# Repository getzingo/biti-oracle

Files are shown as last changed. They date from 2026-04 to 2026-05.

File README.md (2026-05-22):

# Das Orakel von Selphi

Spaßprojekt für BITI Mobile Computing, Wahrsager-Automat mit problematischer Persönlichkeit. Die Schicksale werden von einem Large Language Model freier Wahl kreiert und über das grafische User Interface angezeigt.
Damit die Wahrsagungen individuelle bleiben, wird bei der Aktivierung durch einen Distanz-Messer auf einer dafür vorgesehenen Interaktionsfläche, die Distanz der Hand zum Sensor gemessen und die Temperatur der Handfläche. Kombiniert ergibt sich ein normalisierter Wert, der die Persönlichkeit des Orakels ergibt. Weiters werden die Ausgaben desselben Tages an das KI-Modell übermittelt, damit sich die Wahrsagungen immer voneinander unterscheiden.

Die Anforderungen sind sehr simpel gestaltet, eine interagierende Person soll durch die Text-Hinweise auf dem Bildschirm eine Lesung lostreten, nachdem die Generierung abgeschlossen ist, wird das Schicksal verlautbart und nach einer festgelegten Zeit gelangt das Programm wieder in den Startzustand zurück und wartet auf die nächste Aktivierung.

---

## Architektur

```mermaid
flowchart TB

    subgraph Raspberry
        direction TB
        A[Ultraschall Sensor</br>GPIO 16/12]
        B[Arduino</br>/dev/ttyUSB0]
        C[IR Temp Sensor</br>A6=OBJ A7=SUR]
        
        D[Pygame GUI]
        E[Fortune]
        F[DB]
        G[SensorManager]

        B --> C
        G --> B
        G --> A
        D --> E
        D --> G
        E --> F
    end
    E -->API
    API --> DB
    API --> LLM

```

**SensorManager** (`utils/sensor_manager.py`) ist die zentrale Schaltstelle. Wenn `BOARD=raspi` gesetzt ist, werden echte Sensoren verwendet — sonst simulierte Zufallswerte für Entwicklung und Tests.

**Fortune** (`utils/classes/Fortune.py`) orchestriert die Generierung: Sensorwert → Persönlichkeit (mood) → Prompt → REST API → Ergebnis. Läuft in einem eigenen Thread, damit die GUI nicht blockiert.

**Fallback**: Schlägt die API fehl, greift das Orakel auf frühere, lokal gespeicherte Wahrsagungen aus der SQLite-Datenbank zurück.

## Hardware Komponenten

| Komponente | Details |
|---|---|
| Raspberry Pi 4 | Hauptrechner, GPIO, USB-Host |
| HDMI Display | Vollbild-GUI |
| HC-SR04 | Ultraschall-Distanzsensor (Hand-Erkennung) |
| Seeed Studio Grove IR Sensor v1.2 | Infrarot-Temperatursensor |
| Arduino Nano Klon (CH340) | ADC-Wandler: analog → digital → USB-Seriell |
| 3D-gedruckte Abdeckung | Gehäuse-Oberseite |

Raspberry Pi, Bildschirm und Distanzsensor sind Teil des Joy-IT Raspberry Pi Koffers.

## Software Komponenten

| Komponente | Zweck |
|---|---|
| [Raspberry Pi OS Lite (Debian 13)](https://www.raspberrypi.com/software/operating-systems/) | Base-OS |
| Python 3 | Applikationssprache |
| Pygame 2.x | Grafisches User Interface |
| FastAPI | REST API Server für LLM-Routing |
| OpenAI Python Client | LLM-Kommunikation (OpenAI-kompatibel) |
| Arduino CLI | Kompilieren & Flashen des IR-Sensor-Sketches |
| Docker | Containerisiertes API-Server-Image |
| SQLite | Lokale Fallback-Datenbank |

---

## Schritt-für-Schritt Anleitung

Vorraussetzung sind: 
- ein Raspberry Pi mit Raspberry Pi OS
- Per HDMI angeschlossenes Display
- Seeed grove IR Temperatur Sensor
- HC-SR04 Ultraschall Distanzsensor
- Arduino (in diesem Szenario ein Arduino nano Klon)

### 1. Dependencies

Installation per
```shell
sudo apt-get update
sudo apt-get install -y \
  python3-dev \
  python3-pygame \
  python3-dotenv \
  gcc \
  libgpiod-dev \
  swig \
  liblgpio-dev \
  libegl1 \
  libegl-mesa0 \
  libgles2 \
  libgbm1 \
  libdrm2 \
  git
```

**Wichtig**: `python3-pygame` aus den apt-Repositories installieren, nicht per pip. Das apt-Paket ist gegen die systemweiten SDL2-Bibliotheken gelinkt und funktioniert zuverlässig mit Hardware-Beschleunigung.

---

### 2. Arduino CLI installieren

Der Arduino Nano braucht die `arduino-cli` zum Kompilieren und Flashen. Man kann es aber auch per Arduino IDE von einem anderen Rechner flashen.

```shell
# Binary herunterladen
curl -fsSL https://raw.githubusercontent.com/arduino/arduino-cli/master/install.sh | BINDIR=/usr/local/bin sh

# AVR Core für Arduino Nano installieren
arduino-cli core install arduino:avr

# Prüfen
arduino-cli version
```
---

### 3. Repository klonen

```shell
git clone https://github.com/getzingo/biti-oracle.git
cd the-oracle
```

---

### 4. Python Virtual Environment

Es ist üblich virtuelle Umgebungen für Python Entwicklung zu nehmen, um nicht das OS zu korrumpieren.

```shell
### Im Ordner des Python Projekts
# Komponenten kreieren
python3 -m venv venv

# Venv aktivieren
source venv/bin/activate

# Deaktivieren
deactivate
```

---

### 6. Umgebungsvariablen konfigurieren

Die Datei `env` im Projekt-Root muss angelegt werden (sie ist nicht in Git, weil sie Secrets enthält):

```shell
cp env.example env   # falls vorhanden, sonst händisch:
```

```ini
# env im Projekt-Root
ORACLE_API_SERVER_URL=https://<API-SERVER-IP>:<PORT>/
ORACLE_API_SERVER_TOKEN=<TOKEN>
BOARD=raspi
```

Falls der API-Server lokal auf demselben Pi läuft:
```ini
ORACLE_API_SERVER_URL=http://127.0.0.1:<PORT>/
```

**`BOARD=raspi`** ist der Schalter: Nur wenn diese Variable gesetzt ist, werden echte GPIO- und serielle Sensoren verwendet. Ohne sie läuft das Orakel im Simulationsmodus (Zufallswerte), wichtig für Development.

---

### 7. Verdrahtung

#### Arduino & Temperatur-Sensor

| Grove Pin | Farbe | Funktion | Arduino Pin |
|---|---|---|---|
| 1 | Rot | VCC (3–5V) | 5V |
| 2 | Schwarz | GND | GND |
| 3 | Gelb | OBJ (Objekttemperatur) | A6 |
| 4 | Weiß | SUR (Umgebungstemperatur) | A7 |

Arduino per USB-Kabel mit dem Raspberry Pi verbinden. Nach dem Einstecken sollte `/dev/ttyUSB0` erscheinen:

```shell
ls -la /dev/ttyUSB0
# crw-rw---- 1 root dialout ... /dev/ttyUSB0
```

Falls nicht: `dmesg | tail -20` zeigt an, ob der CH340-Chip erkannt wurde.

#### Ultraschall-Distanzsensor (HC-SR04)

Im Joy-IT Pi-Koffer ist der HC-SR04 bereits fix mit dem Raspberry Pi verbunden:

| HC-SR04 Pin | Raspberry Pi GPIO (BCM) |
|---|---|
| VCC | 5V (Pin 2) |
| GND | GND (Pin 6) |
| Trig | GPIO 16 (Pin 36) |
| Echo | GPIO 12 (Pin 32) |

### 8. Arduino Sketch flashen

Der Sketch `utils/ir_sensor/ir-read.ino` liest A6 und A7 im 1-Sekunden-Takt, mittelt über 10 Samples und sendet die Werte als Textzeile über die serielle Schnittstelle:

```
IR:A6=450,A7=512
IR:A6=451,A7=513
...
```

Wie man das Arduino per CLI flasht, ist etwas komplizierter, [offizielle Docs](https://docs.arduino.cc/arduino-cli/) konsultieren!

Einfacher geht es mit der [offiziellen IDE](https://docs.arduino.cc/software/ide/).

Das Skript sucht automatisch nach dem Arduino-Port. Ausgabe sollte so aussehen:

```
[INFO]  Looking for Arduino on /dev/ttyUSB0 ...
[INFO]  Compiling sketch ...
[INFO]  Uploading to /dev/ttyUSB0 ...
[INFO]  Flash complete! Board should start sending data at 9600 baud.
```

Testen ob Daten ankommen:

```shell
python3 -c "import serial; s=serial.Serial('/dev/ttyUSB0', 9600, timeout=2); print(s.readline())"
# b'IR:A6=448,A7=510\r\n'
```

---

### 9. IR Sensor kalibrieren

Der Sensor meldet Rohwerte (0–1023), die in °C umgerechnet werden müssen. Die Kalibrierung erfolgt in zwei Stufen:

**a) Umgebungstemperatur (NTC-Thermistor an A7)**

Der Sketch liest A7, die `calibration.py` rechnet den ADC-Wert über die NTC-Widerstandstabelle in °C um. Der Parameter `temp_calibration` in `sensor_manager.py` korrigiert die Selbst-Erwärmung des NTC. Standard ist `-2.6` (ermittelt bei 24.5°C Raumtemperatur).

**b) Objekttemperatur (Thermopile an A6)**

Die Thermopile-Spannung wird über eine [2D-Lookup-Tabelle des Herstellers](https://github.com/Seeed-Studio/Digital_Infrared_Temperature_Sensor_MLX90615) (13×12 Matrix, -10°C bis 110°C) in Objekttemperatur übersetzt.
Die Kalibrierparameter stehen in `utils/ir_sensor/config.yaml`:

```yaml
reference_vol: "0.472"   # Thermopile-Nullpunkt (V)
offset_vol: "0.014"      # Kalibrier-Offset (V)
temp_range: "10.0"       # Temperaturschritt der Tabelle
```

**So kalibriert man den Sensor neu:**

1. Raumtemperatur mit einem Referenzthermometer messen (z.B. 22.5°C)
2. `python3 utils/ir_sensor/sensor.py` laufen lassen
3. Die `ambient_c`-Werte beobachten. Weichen sie ab, `temp_calibration` im `SensorManager` anpassen
4. Eine Hand vor den Sensor halten. `object_c` sollte ~2°C über der Umgebung liegen
5. Passt der Nullpunkt nicht, `reference_vol` in `config.yaml` justieren

Die aktuellen Werte sind kalibriert für den ATmega168 Nano-Klon bei 24.5°C Raumtemperatur (Mai 2026).

---

### 10. API Server aufsetzen

Der API-Server (`utils/api/server/oracle_api.py`) ist eine FastAPI-Applikation, die eingehende Fortune-Anfragen entgegennimmt,
an ein LLM weiterleitet und das Ergebnis zurückgibt.
Er kann lokal auf dem Pi direkt ausgeführt werden oder auf einem separaten Server laufen.
Als Client wird die Library Openai verwendet, sehr viele Provider sind kompatibel mit diesem Protokoll.

Der Server braucht ein paar ENVs damit er läuft, zB. für OpenAI API:

```ini
# utils/api/server/env
DEV_MODE=False
OAI_TOKEN=sk-dein-llm-api-key
OAI_COMPATIBLE_API_URL=https://api.openai.com/v1
OAI_MODEL=gpt-4o
ORACLE_API_SERVER_TOKEN=<GLEICHER TOKEN WIE Fortune()>
```

**DEV_MODE=True** deaktiviert die HMAC-Signatur-Prüfung, für lokale Setups ok. Für öffentliche Adressen auf `False` setzen.

Um das Dockerfile im Repo zu verwenden für ein containerisiertes Deployment:

```shell
# Image bauen
docker build -t oracle-api:latest -f Dockerfile .

# Container starten
docker run -d \
  --name oracle-api \
  -p <EXTERNER PORT>:80 \
  -e DEV_MODE=False \
  -e OAI_TOKEN=sk-dein-llm-api-key \
  -e OAI_COMPATIBLE_API_URL=https://api.openai.com/v1 \
  -e OAI_MODEL=gpt-4o \
  -e ORACLE_API_SERVER_TOKEN=<GLEICHER TOKEN WIE Fortune()> \
  oracle-api:latest

# Logs prüfen
docker logs -f oracle-api
```

---

### 11. GUI starten — Das Orakel läuft

```shell
cd ~/the-oracle
source venv/bin/activate
BOARD=raspi python3 main.py
```

Das Orakel startet im Vollbild. Der Ablauf:

1. **Idle**: Titelbildschirm mit Kristallkugel, Sternen, Pyramide mit Auge. Die blinkende Aufforderung „~ Bitte Hand auflegen ~" erscheint.
2. **Sensing**: Hand wurde erkannt (Ultraschall). Eine zufällige Dauer zwischen `sensing_min_duration_seconds` und `sensing_max_duration_seconds` (konfigurierbar in `config.yaml`, default 3–15s). Währenddessen pulsiert die Kristallkugel und zufällige Sprüche wie „Hmmmm" oder „Wow, spiritually valuable!" erscheinen. Parallel startet bereits die Fortune-Generierung per API.
3. **Generating**: Das Orakel konsultiert das Jenseits. Die GUI zeigt „THE ORACLE is about to speak ...". Sobald die API-Antwort da ist (oder der Timeout greift), wechselt die Anzeige.
4. **Fortune**: Die Wahrsagung wird bildschirmfüllend angezeigt — mit Gold-Text auf violett-orange-farbenem Gradient-Hintergrund. Nach `display_fortune_duration_seconds` (default 30s) zurück zu Idle.

**Beenden**: `ESC` oder `Ctrl+C`.

---

### 12. Prompt-Persönlichkeiten

Die 5 Persönlichkeiten des Orakels sind in `utils/api/client/MoodInstructions.py` definiert. Jede hat eigene Beispiel-Sprüche und Stil-Vorgaben:

| Sensorwert | Stimmung | Charakter |
|---|---|---|
| 0–20 | gentle | Sanft, fürsorglich — das Grauen kommt leise |
| 21–40 | dramatic | Theatralisch, monumentale Ernsthaftigkeit |
| 41–60 | cynical | Müde, abgeklärt — „Ich hab das alles schon gesehen" |
| 61–80 | chaotic | Assoziativ, traumlogisch — „etwas im Getränkeautomaten weiß deinen Stundenplan" |
| 81–100 | obliterating | Skalpell-scharf — nennt den wahren Charakterfehler |

Kalte Hände (0–20) bedeuten also ein sanftes Orakel, warme Hände (81–100) ein vernichtendes. Der Prompt enthält harte Regeln: *ein Satz, maximal 25 Wörter, keine Emojis, nicht mit "I" beginnen, nur die Prophezeiung ausgeben.*

Die Beispiele aus den MoodInstructions lohnen sich zu lesen — sie geben den Ton vor:

> *„The version of you that finishes things lives in a different timeline."* (obliterating)
> *„The library printer saved one copy. It is still there."* (gentle)

---

## Gehäuse & 3D-Druck

Die Oberseite des Orakels ist ein 3D-gedrucktes Cover. Die STL-Dateien sind Teil des Repos. Die Grundfläche sollte folgende Aussparungen haben:

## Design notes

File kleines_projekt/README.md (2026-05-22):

# RPi kleines Projekt

## Infos

### Environment

- JoyPi mit Raspberry Pi 4B
- RPi OS trixie
- Python 3.13.5
- DHT11 Sensor auf Pin7 (GPIO4)
- HC-SR04 Ultraschall Distanzsensor: Trigger auf Pin32

### Auswahlkriterien

Für das "große Projekt" müssen ein paar Sensoren betrieben werden, deswegen habe ich diese in Kombination mit Pygame getestet.

Es ist eine ganz simple GUI mit zwei States, die bei Interaktion wechseln. Der Splashcreen ist `idle` und beinhaltet ein *schwebendes* Textelement.
State `measuring` liest die Sensoren aus und rendert die Daten dann auf den Screen.

In der gleichen Form soll das dann im großen Projekt passieren, nur mit mehr Spielereien.

### Ziele/Nicht Ziele

Das Ziel wurde unter anderem schon unter [Auswahlkriterien](#auswahlkriterien) beschrieben. Zusätzlich kommt aber noch dazu, dass ich keine Desktop Environment installieren möchte, um Ressourcen für die später eingesetzte LLM zu belegen, Zugriff passiert hauptsächlich ohnehin nur über SSH.
Nicht Ziele orientieren sich an den Zielen, es ist ein simples Setup, das nur die Interaktion zwischen Pygame und Sensoren darstellen soll.

### Hürden & RTFM

Ursprünglich sollte der Seeed Grove IR Temperatursensor die Messungen übernehmen, das erlag aber leider dem Problem, dass der RPi keine Analog-In Pins besitzt. Und ohne ADC musste der DHT11 als Temperatursensor verwendet werden.

Am schwierigsten war das Rendern von Pygame Inhalten auf den Screen ohne GUI. Claude Opus konnte das Problem nicht lösen, früher (unter Buster) konnte man einfach den richtigen Display mit `export DISPLAY=:0.0` setzen und dann konnte man auf diesen Display Inhalte rendern.

Das ging allerdings bei dem Versuch nicht so straight-forward.

Die erste Fehlerquelle war, dass ich das Package `pygame` mit pip in einer Virtuellen Environment installiert habe. [Das soll man aber nicht machen, sondern das OS-Package installieren.](https://www.pygame.org/wiki/GettingStarted#Unix%20Binary%20Packages)

`python3-pygame` und pip package `pygame` haben dieselbe Version schlussendlich:
```bash
apt policy python3-pygame
# python3-pygame:
#   Installed: 2.6.1-1+b2
#   Candidate: 2.6.1-1+b2
#   Version table:
#  *** 2.6.1-1+b2 500
#         500 http://deb.debian.org/debian trixie/main arm64 Packages
#         100 /var/lib/dpkg/status

pip3 index versions pygame
# pygame (2.6.1)
# Available versions: 2.6.1, 2.6.0, 2.5.2, 2.5.1, 2.5.0, 2.4.0, 2.3.0, 2.2.0, 2.1.3, 2.1.2, 2.1.1, 2.1.0, 2.0.3, 2.0.2, 2.0.1, 2.0.0, 1.9.6, 1.9.5, 1.9.4, 1.9.3, 1.9.2
#   INSTALLED: 2.6.1
#   LATEST:    2.6.1
```

Leider hat das pip package keine richtige Implementierung um den Kernel Mode-Setting Direct Rendering Manager (KMSDRM) mit dem Wayland Video Treiber zu verwenden, pygame wollte immer auf X11 zurückgreifen ([Quelle](https://forums.raspberrypi.com/viewtopic.php?t=367519 )). Deswegen über den OS Package Manager mit den Dependencies für das SDL Backend.

```bash
pip3 uninstall pygame
apt install python3-pygame libegl1 libegl-mesa0 libgles2

# Deswegen in venv/bin/activate richtigen Treiber einfügen
echo 'export SDL_VIDEODRIVER=kmsdrm' >> venv/bin/activate
```

Weiters muss man die Virtuelle Umgebung dann mit OS Package Referenz kreieren: 
```bash
python3 -m venv venv --system-site-packages
```

Es kann sein, dass man sich das alles mit der default Desktop Umgebung ersparen würde, es hat mich aber eh nur 3 Stunden gekostet.

## Installation

Voraussetzung ist ein funktionierender RPi, gearbeitet wurde unter dem OS `Raspberry Pi OS Lite`, der auf Debian 13 (trixie) basiert.

```bash
sudo apt-get update
sudo apt-get install -y \
  python3-dev \
  python3-pygame \
  python3-dotenv \
  gcc \
  libgpiod-dev \
  swig \
  liblgpio-dev \
  libegl1 \
  libegl-mesa0 \
  libgles2 \
  libgbm1 \
  libdrm2 \
  git
```

Der aktuelle User **muss** in den Gruppen `video, render, input, gpio, i2c, spi` sein:

```bash
USER=$(whoami)
sudo usermod -aG video,render,input,gpio,i2c,spi $USER
```

Dann dieses Repo klonen und den Projektordner wechseln. Anschliessend virtuelle Umgebung initialisieren und Pip Abhängigkeiten installieren:

```shell
git clone https://github.com/getzingo/biti-oracle
cd biti-oracle/kleines_projekt

# Venv initialisieren
python3 -m venv venv --system-site-packages
# DSM workaround
echo 'export SDL_VIDEODRIVER=kmsdrm' >> venv/bin/activate
source venv/bin/activate
```

Dann sollte in der Shell immer `venv` voranstehen, um zu signalisieren, dass die virtuelle Umgebung aktiv ist. Die meisten Betriebssysteme lassen es nämlich nicht zu, direkt Pip-Packages zu installieren. Für Python Module, die global verwendet werden müssen, sollte man immer den OS Packagemanager verwenden, wie etwa `apt install python3-dotenv`.

Um alle Python Module zu installieren, das bereitgestellte File `requirements.txt` verwenden:

```bash
pip3 install -r requirements.txt

# Zur Sicherheit nochmal pygame deinstallieren
pip3 uninstall pygame
```

### Demo ausführen

Es gibt auch ein Shell-Script um nicht diesen ganzen Prozess durchführen zu müssen:

```bash
./run-demo.sh

# Oder mit aktiver venv
python kleines_projekt_demo.py
```

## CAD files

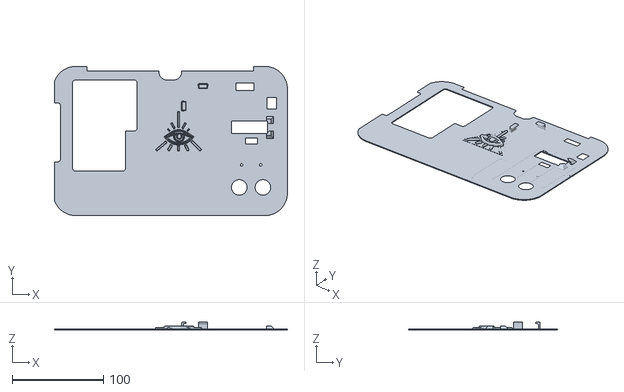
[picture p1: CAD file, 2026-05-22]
3d-print/the-oracle.stl
256.0 x 164.0 x 9.00

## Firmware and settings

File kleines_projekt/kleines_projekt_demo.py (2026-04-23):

import math
import time
import yaml
import RPi.GPIO as GPIO
import board
import adafruit_dht
import pygame

with open("config_klein.yaml", 'r') as f:
    config = yaml.safe_load(f)

SCREEN_WIDTH = config["pygame-config"]["SCREEN_WIDTH"]
SCREEN_HEIGHT = config["pygame-config"]["SCREEN_HEIGHT"]
FPS = config["pygame-config"]["FPS"]
FULLSCREEN = config["pygame-config"]["FULLSCREEN"]

class ProjektKlein:
    STATE_IDLE = "idle"
    STATE_MEASURING = "measuring"

    def __init__(self):
        pygame.init()
        flags = pygame.FULLSCREEN if FULLSCREEN else 0
        self.screen = pygame.display.set_mode((SCREEN_WIDTH, SCREEN_HEIGHT), flags=flags, display=0)
        self.t_secs = 0
        pygame.display.set_caption("Kleines Projekt Demo")

        self.font_title = pygame.font.SysFont("monospace", 60)
        self.font_text = pygame.font.SysFont("monospace", 70)

        self.bg = pygame.Surface(self.screen.get_size())
        self.bob = 0
        self.state = self.STATE_IDLE


        # ultrasonic sensor setup
        self.PIN_TRIG = 16
        self.PIN_ECHO = 12
        GPIO.setmode(GPIO.BCM)
        GPIO.setup(self.PIN_TRIG, GPIO.OUT)
        GPIO.setup(self.PIN_ECHO, GPIO.IN)
        GPIO.output(self.PIN_TRIG, GPIO.LOW)
        time.sleep(0.5)
        self.movement_detection_range = 35.0
        self.movement_detection_interval = 5
        self.stagnated_movement = []

        # DHT11 setup
        self.dht_device = adafruit_dht.DHT11(board.D4)


        self.current_distance = self.get_distance()
        self.baseline_distance = self.current_distance
        self.distance_threshold = 50.0

        self.current_temp = "--"
        self.current_hum = "--"
        self.last_sensor_read = 0

    @staticmethod
    def calibrate_distance(raw_distance: float, measured_50: float = 48.5, measured_100: float = 98.5, max_distance: float = 400.0):
        if raw_distance > max_distance:
            return 0.0
        calibration_points = [
            (0.0, 0.0),
            (measured_50, 50.0),
            (measured_100, 100.0),
        ]

        for d in range(len(calibration_points) - 1):
            raw_low, true_low = calibration_points[d]
            raw_high, true_high = calibration_points[d+1]
            if raw_low <= raw_distance <= raw_high:
                t = (raw_distance - raw_low) / (raw_high - raw_low)
                return round(true_low + t * (true_high - true_low), 2)

        raw_low, true_low = calibration_points[-2]
        raw_high, true_high = calibration_points[-1]
        t = (raw_distance - raw_low) / (raw_high - raw_low)
        return round(true_low + t * (true_high - true_low), 2)

    def movement_detection(self, distance: float) -> bool:
        print(f"Distance: {distance:.2f} cm")
        print(f"Gathered: {self.stagnated_movement}")
        if len(self.stagnated_movement) < self.movement_detection_interval:
            self.stagnated_movement.append(distance)
            return False
        if len(self.stagnated_movement) == self.movement_detection_interval:
            if (max(self.stagnated_movement) - min(self.stagnated_movement)) < self.movement_detection_range and distance > self.distance_threshold + 25.0:
                self.stagnated_movement = []
                return True
        self.stagnated_movement = self.stagnated_movement[1:] + [distance]
        return False


    def get_distance(self):
        # Send 10us pulse to trigger
        GPIO.output(self.PIN_TRIG, GPIO.HIGH)
        time.sleep(0.00001)
        GPIO.output(self.PIN_TRIG, GPIO.LOW)

        pulse_start_time = time.time()
        pulse_end_time = time.time()
        timeout = time.time() + 0.1

        while GPIO.input(self.PIN_ECHO) == 0 and time.time() < timeout:
            pulse_start_time = time.time()

        while GPIO.input(self.PIN_ECHO) == 1 and time.time() < timeout:
            pulse_end_time = time.time()

        pulse_duration = pulse_end_time - pulse_start_time
        distance = round(pulse_duration * 17150, 2)

        if self.state == self.STATE_MEASURING:
            if self.movement_detection(distance):
                self.state = self.STATE_IDLE

        return self.calibrate_distance(distance)

    def read_dht(self):
        try:
            temp = self.dht_device.temperature
            hum = self.dht_device.humidity
            if temp is not None and hum is not None:
                self.current_temp = temp
                self.current_hum = hum
        except RuntimeError as error:
            # Too many errors while reading
            pass

    def draw_centered_text(
            self,
            text: str,
            font: pygame.font.Font = None,
            y_offset: int=0,
            color=(250,250,250)
        ):
        """
        Helper function to draw centered text on screen, font from self.font
        :param text: String text to be drawn
        :param font: Optional pygame.font.Font object
        :param y_offset: Integer offset of y-axis
        :param color: Color of text in RGB tuple
        :return: None
        """
        if not font:
            # normal text
            text_surf = self.font_text.render(text, True, color)
            y = (self.screen.get_height() - text_surf.get_height()) / 2 + self.bob
        else:
            # title text
            text_surf = font.render(text, True, color)
            y = (self.screen.get_height() - text_surf.get_height()) / 2
        x = (self.screen.get_width() - text_surf.get_width()) / 2
        self.screen.blit(text_surf, (x,y + y_offset))


    def draw_idle_screen(self):
        self.screen.fill((15, 15, 15))
        # (delta_time * speed) * amplitude
        self.bob = math.sin(self.t_secs * 1.5) * 10
        self.draw_centered_text("MOBC Demo",font=self.font_title, y_offset=-150)
        self.draw_centered_text("Hand über Sensor halten", y_offset=60)

    def draw_measuring_screen(self):
        self.screen.fill((15, 15, 15))
        self.bob = 0

        # Throttle sensor reads to once every 2 seconds
        current_time = time.time()
        if current_time - self.last_sensor_read > 2.0:
            self.current_distance = self.get_distance()
            self.read_dht()
            self.last_sensor_read = current_time

        self.draw_centered_text("Messung Aktiv", font=self.font_title, y_offset=-200)
        self.draw_centered_text(f"Distanz: {self.current_distance} cm", y_offset=-50)
        self.draw_centered_text(f"Temp: {self.current_temp} C", y_offset=50)
        self.draw_centered_text(f"Luftf: {self.current_hum} %", y_offset=150)

    def run(self):
        running = True
        clock = pygame.time.Clock()
        while running:
            delta_time = clock.tick(FPS) / 1000
            self.t_secs += delta_time

            for event in pygame.event.get():
                if event.type == pygame.QUIT:
                    running = False
                if event.type == pygame.KEYDOWN:
                    if event.key == pygame.K_ESCAPE:
                        running = False
                    if event.key == pygame.K_SPACE:
                        self.state = ProjektKlein.STATE_MEASURING
            if self.state == self.STATE_IDLE:
                self.draw_idle_screen()

                # measure when interrupted
                current_distance = self.get_distance()
                if abs(current_distance - self.current_distance) > self.distance_threshold:
                    self.state = self.STATE_MEASURING
                    # reset readout time
                    self.last_sensor_read = 0

            elif self.state == self.STATE_MEASURING:
                self.draw_measuring_screen()

            pygame.display.flip()

        GPIO.cleanup()
        pygame.quit()

if __name__ == "__main__":
    try:
        p = ProjektKlein()
        p.run()
    except KeyboardInterrupt:
        GPIO.cleanup()

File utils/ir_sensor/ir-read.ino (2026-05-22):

// Arduino Nano IR Temperature Sensor Reader
// Seeed Studio Grove IR Temperature Sensor v1.2
// Uses INTERNAL 1.1V reference for ADC (manufacturer spec)
// A6 = OBJ (object temperature, thermopile)
// A7 = SUR (ambient temperature, NTC thermistor)

const int OBJ_PIN = A6;  // object temperature (thermopile)
const int SUR_PIN = A7;  // surrounding temperature (NTC)
const int SAMPLES = 10;

void setup() {
  Serial.begin(9600);
  analogReference(INTERNAL);  // 1.1V internal reference
  delay(100);
}

void loop() {
  long sum_obj = 0, sum_sur = 0;
  for (int i = 0; i < SAMPLES; i++) {
    sum_obj += analogRead(OBJ_PIN);
    sum_sur += analogRead(SUR_PIN);
    delay(5);
  }
  int avg_obj = sum_obj / SAMPLES;
  int avg_sur = sum_sur / SAMPLES;

  // Format: IR:A6=obj_val,A7=sur_val
  Serial.print("IR:");
  Serial.print("A6=");
  Serial.print(avg_obj);
  Serial.print(",A7=");
  Serial.println(avg_sur);

  delay(1000);
}
